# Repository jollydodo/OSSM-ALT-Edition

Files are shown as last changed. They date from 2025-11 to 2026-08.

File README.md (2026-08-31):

# OSSM ALT Edition
---
## 🎯 Overview

OSSM ALT Edition is a community-driven alternative version of the well-known [OSSM](https://github.com/KinkyMakers/OSSM-hardware) platform. A lot of time and effort has gone into this project. This has been possible thanks to all the previous work that has been done and several community members that helped test this. Do note that we are still in 'beta testing' phase and that you may run into issues. Please provide feedback to help improve the project. This project represents a ground-up redesign focused on:

- **Modern Power Delivery**: Custom 28V 140W USB-C PCB with comprehensive protection circuits
- **Simplified Assembly**: All-in-one clean design with easily sourceable components
- **European Sourcing**: BOM optimized for availability in Europe
- **Enhanced Performance**: Support for MGN12H and MGN15H rails with support for belts up to 15mm belt.
- **Open Source**: Fully open hardware

***Links***: KM [Discord community](https://kinkymakers.com) & [Ko-Fi](https://ko-fi.com/dododesigns) (for contributions / buying boards)

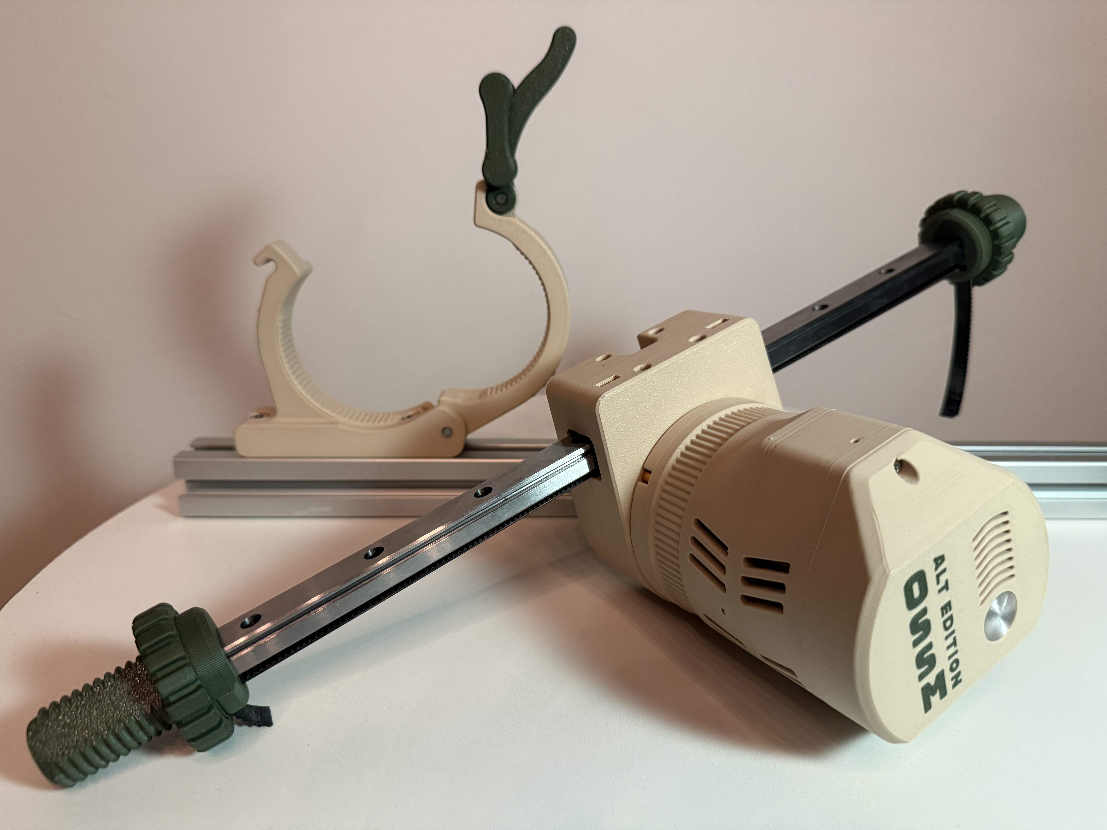
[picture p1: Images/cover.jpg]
MGN15H version with new clamp


<sub>**Notice**: This version was developed without any involvement of the original OSSM / Research and Desire members. However, none of this would have been possible without their prior work which is greatly appreciated. Especially the work of [ArmpitMFG](https://github.com/armpitMFG) has been a great inspiration. </sub>

---

## ✨ Key Features

### Hardware Improvements
- **Custom 28V USB-C PCB** with extensive protection circuits
  - Over/under voltage protection
  - Reverse current protection
  - ESD protection on all exposed ports
  - Inrush current limiting
  - Hybrid polymer capacitors for stable power
  - Brake Chopper Add-On 360Watt
- **Dual Rail Options**
  - MGN15H for heavy-duty applications (up to 15mm belts)
  - MGN12H for lighter builds (up to 12mm belts)
- **Efficient Travel**: Rail length minus 150mm usable stroke
- **Compatible with Pitclamp Mini** and includes optimized alternative design with dowels

### Electronics & Firmware
- **ESP32-S3** microcontroller with integrated RS485 controller
- **WS2812 Status LED** (firmware support pending)
- **Made for [OSSM Rust](https://github.com/orange-gem/ossm-rs)** firmware
- Compatible with step/dir control for original firmware adaptation
- **Optional Brake Chopper PCB** for enhanced safety

### Design Philosophy
- Optimized for 3D printing (minimal supports required)
- Common, easily sourceable components
- Clean, simple assembly
- Comprehensive protection systems

---
  
## 📦 Bill of Materials

A comprehensive BOM with descriptions and links can be found [here](Assembly-Info/BOM-OSSM-ALT.csv). However, the parts below are a quick summary everything you need for building this complete version:

| **Part** | **Description** | **Costs** |
| --- | --- | ----- |
| 57AIM30 | Motor | €110  |
| MGN15H Rail | Rail 40cm | €25 |
| Or MGN12H Rail | Rail 40cm | €21 |
| 625RS Bearing  | Belt Bearings | €15 |
| M5 Bolts | Complete kit | €12 |
| M3 Bolts | Complete kit | €12 |
| Dowel Pins | Precision pins | €10 |
| GT2 Belt | 50cm | €15 |
| GT2 20T pulley | 15mm | €10 | 
| Filament  | Max 500g | €20 |
| OSSM ALT 28V PCB | Designs available for self-sourcing or buy through me to support this project. | €40 |
| **Total** | Rough approximation. Check BOM for details. | €270  |

📋 **[Complete BOM with part numbers and links](Assembly-Info/BOM-OSSM-ALT.csv)**

> **Note**: You will also need a remote control device. Compatible options include:
> - Official R&D remote
> - iOS/Android apps
> - Web control interface
> - M5 Remote (check firmware compatibility)

---

## 3D Printing Tips

500 grams of filament should be enough to complete the whole build including the main pitclamp (350 without). It is optimized as much as possible for 3D printing with only 1 part requiring a small amount of supports. The filament type should not matter for most standard build, but heavy users might want to rely on something sturdier like tough-PLA, PET-G, ASA or PC. The test builds have been printed with standard Bambulab basic PLA (Not matte/silk). 

**Filament Required**: ~500g for complete build including Pitclamp

**Recommended Materials**:
- **Standard Use**: PLA, PLA+
- **Heavy Use**: Tough-PLA, PETG, ASA, PC

**Important**: Follow the [detailed 3D printing guide](Assembly-Info/Print-Manual/README.md) carefully to ensure proper fit and function.

**Print Options**:
- Standard version (no branding)
- Multi-color branded version (AMS/toolchanger compatible)
- Single-color embossed version

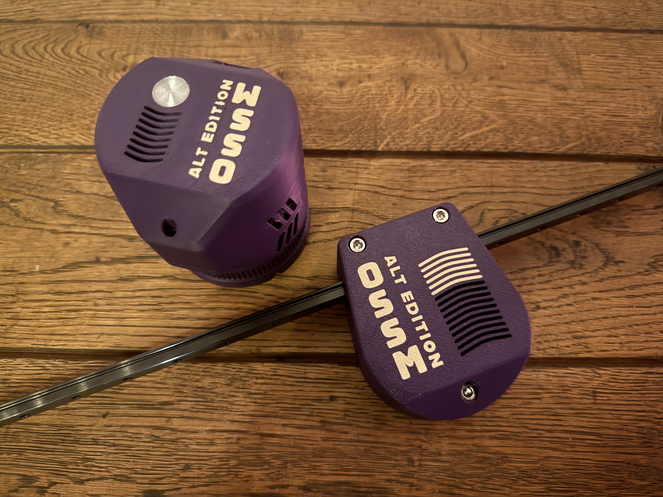
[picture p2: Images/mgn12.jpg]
MGN12H Light version


---
## Assembly:

📺 **Video Assembly Guides**:
- [Part 1](https://youtu.be/EqzNXQzpHu0) 
- [Part 2](https://youtu.be/FnY4Sz64H2A) 

📖 **Written Assembly Guide**: In development

❓ **Frequently asked**: [How do I install the brake chopper?](#how-do-i-install-the-brake-chopper)

💬 **Need Help?** Join the KM [Discord community](https://kinkymakers.com) for assembly support and questions (Look for the OSSM ALT Project).

---

## 🔌 Main PCB Specifications

Most work has gone into this PCB. My vision for this Machine/PCB is that groups of people will self-source this PCB. From 10+ pieces this makes sense, so as long as you can find 10 people you should be able to buy this at an affordable price. The rest of the machine can be printed and uses off the shelf parts. I will also sell these boards for people that only need 1 PCB and want to help support this project (please not that a lot of my own money has gone into this and any support is greatly appreciated ([Ko-Fi](https://ko-fi.com/dododesigns))

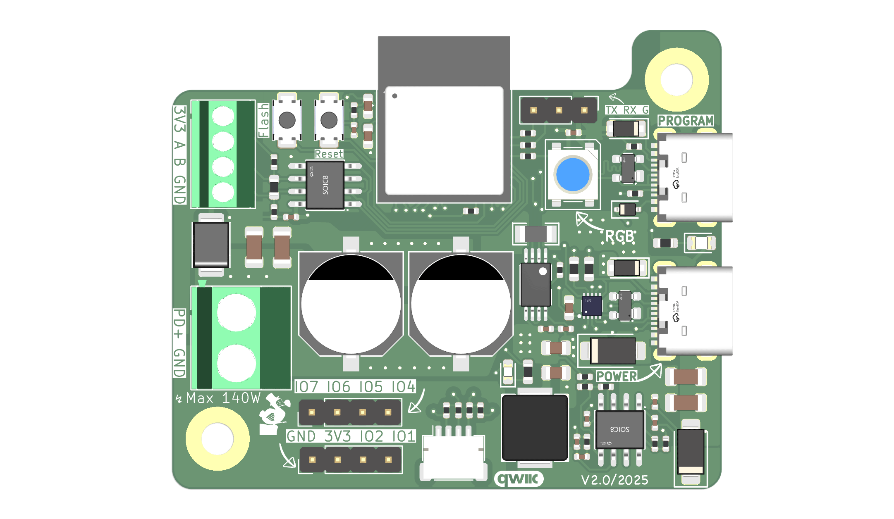
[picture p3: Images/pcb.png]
28V PCB


### Technical Features

- **Power**: CH224Q for 28V USB-C PD 3.2 negotiation
- - Continuous 140Watt capable with 4 layer optimized PCB design (load tested)
- **Controller**: ESP32-S3 microcontroller with onboard antenna
- **Communication**: Integrated RS485 controller
- **Power Protection**:
  - Hybrid polymer capacitors
  - Inrush current limiting
  - Over/under voltage protection
  - Reverse current protection
- **Additional Features**:
  - Dedicated USB-C debugging port
  - ESD protection on all exposed ports
  - WS2812 status LED
  - Brake chopper expansion support

**Design Tool**: KiCAD 9  
**Manufacturing**: Optimized for major PCB fabrication houses

### Optional Brake Chopper Add-on

Brake PCB

Enhanced protection for heavy-duty use:
- **Dissipation**: 12W continuous, 360W short-term spikes
- **Protection Threshold**: 33V (protects 36V TVS diode)
- **Purpose**: Back-EMF spike suppression
- **Recommended For**: Heavy users and added safety margin

This was mainly a fun side project for me which also adds functionality. It is basically an improved version of a Pololu Shunt Regulator, but completely redesigned with an on-board gate driver, 12V LDO, and 12watts of power resistors (2 sides assembly up to 24watt). This PCB was designed to be very cheap and easy to produce. 

Assembly PCB

> 🔧 **Installing it?** See [How do I install the brake chopper?](#how-do-i-install-the-brake-chopper) in the FAQ.

---

## ❓ FAQ

### How do I install the brake chopper?

There are **two** ways to connect the brake chopper to the main PCB. Both are electrically identical — the brake chopper simply sits in parallel with the motor supply.

#### Option 1: Screw terminal (recommended)

Simply put the brake chopper wires into the **same green screw terminal** as the motor power wires: the red (+) wire together with the motor's red wire, and the black (GND) wire together with the motor's black wire. Twist the two wires of each pair together, insert them into the terminal and tighten the screw.

This requires no soldering on the main PCB at all and is the option I recommend for everyone.

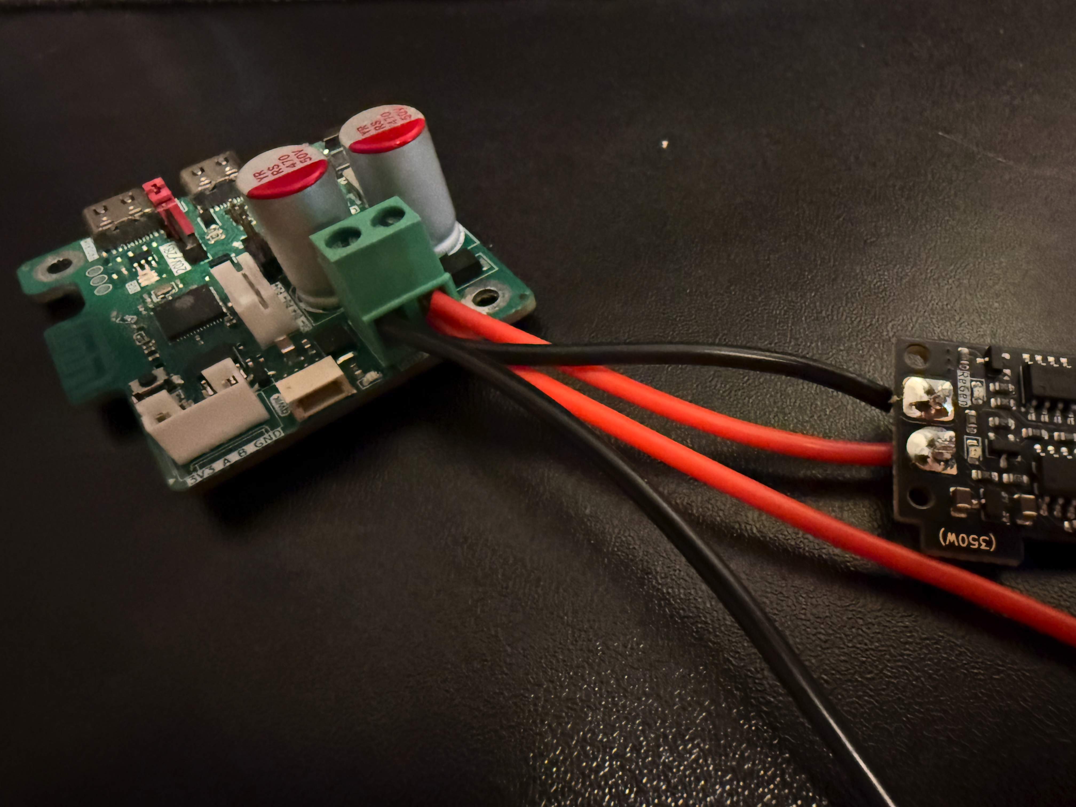
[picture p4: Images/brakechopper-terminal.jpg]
Brake chopper in the screw terminal


<video src="https://github.com/jollydodo/OSSM-ALT-Edition/raw/main/Images/brakechopper-install.mp4" controls width="640"></video>

📺 [Watch the short installation video](https://github.com/jollydodo/OSSM-ALT-Edition/raw/main/Images/brakechopper-install.mp4) *(if the player above does not load)*

#### Option 2: Solder to the dedicated pads

If you don't like doubling up wires in the screw terminal, the main PCB has **two dedicated pads on the back** for the brake chopper, marked `Brake` (`VIN` and `GND`). Solder the red wire to `VIN` and the black wire to `GND`.

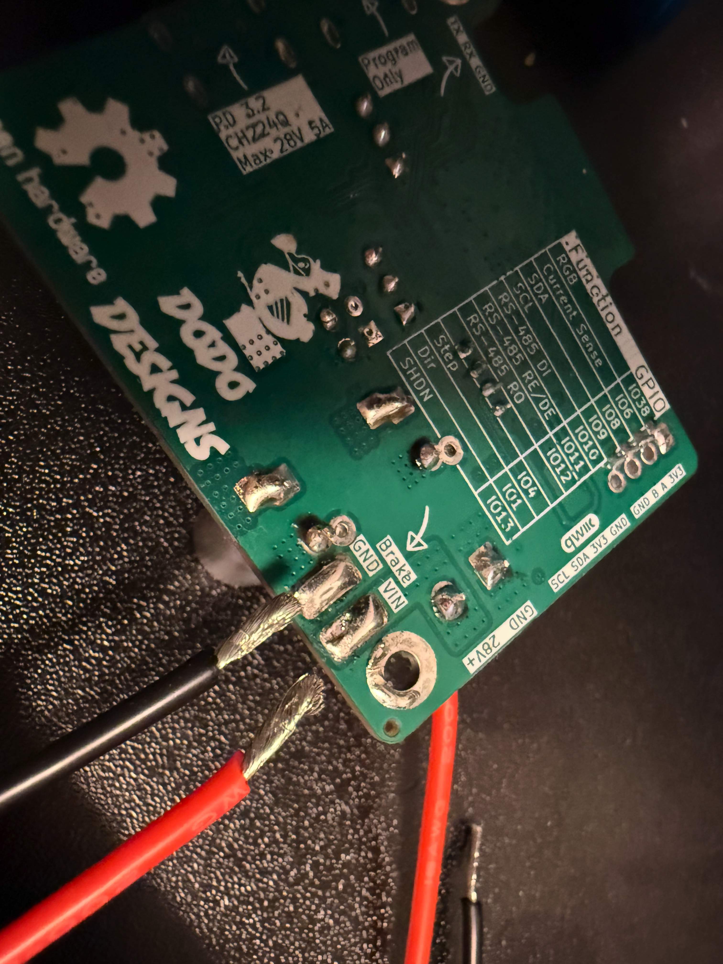
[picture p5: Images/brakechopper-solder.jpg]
Brake chopper soldered to the dedicated pads


> ⚠️ **At your own risk.** This is a 4-layer PCB with large copper planes that pull a lot of heat away from the joint, so you need a decent soldering iron (and patience). Double-check that you have not accidentally bridged anything before applying power.

---
## 🔋 Compatible Power Sources

This design is focused around PD, so it only makes sense to provide some options that are tested.

> **Important**: Use a USB-C cable with E-marker chip for >3A current. Standard cables will limit performance.

### Tested & Confirmed

| Device | Type | Rating | Status | Recommended | Rating | Notes |
|---|---|---|---|---|---|-----|
| [Apple 140W USB-C Adapter](https://www.apple.com/nl/shop/product/mw2m3zm/a/usb%E2%80%91c-lichtnetadapter-van-140-w) | Wall Adapter | 28V / 5A (140W) | 🔬 Tested | ✅ Recommended| ★★★★★ (5)| Excellent reliability and quality, Only ~€60 (will likely not work with other pcb's besides the OSSM ALT since it requires inrush current protection) |
| [Ugreen 200W Powerbank](https://eu.ugreen.com/products/ugreen-nexode-power-bank-200w-25000mah) | Powerbank | 28V / 5A (140W) | 🔬 Tested| ✅ Recommended|★★★★★ (5)| Great portable option that negotiates with almost any chip. Best power bank I have tested.|
| [Ugreen Nexode 145W Powerbank 25000mAh](https://nl.ugreen.com/products/ugreen-140w-power-bank-145w-max-25000mah-externe-batterij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) | Powerbank | 28V / 5A (140W) | 🔬 Tested | ✅ Recommended| ★★★★★ (5)| Tested by community member **Frayd**. Portable option in the same Nexode line as the 200W model above. |
| [Anker 140W Wall Adapter](https://www.anker.com/products/a2697-anker-charger-140w-4-port) | Wall Adapter | 28V / 5A (140W) | 🔬 Tested| ✅ Recommended|★★★★☆ (4)| Works well, but you will definitely feel it get hot at prolonged 140W and after 20 minutes or so it will lower the power to cool down. 100Watts continuous is fine so for the gold motor there are no problems. I have yet to see a supported motor that pulls 140W continuous. 
| [Sitecom 140W Wall adapter](https://www.action.com/nl-nl/p/3221194/sitecom-usb-wandoplader/) | Wall Adapter | 28V / 5A (140W)|🔬 Tested | ✅ Recommended| ★★★★☆ (4) | Cheapest adapter of the list (~€20). Did not do any extensive testing yet, but it negotiates 28V and 20V fine. I was also able to load test it at 140W and you can feel it get warmer similar to the Anker one, but it seems to hold up fine. At it's price point it is probably a very good deal (even comes with a cable), but we don't know if it's easy to source since right now it's sold at 'action' which normally changes its inventory quite quickly. 
| [Ugreen 100W Wall Adapter](https://www.amazon.nl/dp/B091TV6LWN) | Wall Adapter | 20V / 5A (100W) | 🔬 Tested | ⚠️ Lower Power|★★★☆☆ (3) |Works okay, but do notice that this one does not support 28V. If you have the OSSM-Alt pcb at 28V and still try to power it, it will work but negotiates down to 20V. |
| [Framework 180W Adapter](https://frame.work/nl/en/products/16-power-adapter?v=FRANCR000F) | Wall Adapter | 36V / 5A (180W) | 🔬 Tested | ⚠️ Lower Power | ★★★☆☆ (3) | Quality wise I believe this is a good adapter, but it has a lot of difficulty negotiating with several common cheap PD chips. So it won't negotiate above 20V on the OSSM-ALT PCB and it also does not seem to support I2C with this chip either. Therefore, not really recommended unless you already have it and just power a motor at max 100W. 
| Apple 67W Adapter | Powerbank | 20V / 3.3A (67W) | 🔬 Tested | ⚠️ Lower Power | ★★☆☆☆ (2.5) | Negotiates well and also supports I2C negotiation. 67W is however on the lower side, so this is definitely not recommended for heavy usage. Still, this was the adapter I first tested my OSSM with and from my experience 67W is enough for most light play.  |
| Xiaomi Mi 50W | Powerbank | 20V / 2A (40W) | 🔬 Tested | ⚠️ Low Power | ★★☆☆☆ (2) | Not recommended. Negotiates well, but low power. Still for a very light weight OSSM it might. be fine.  |

**Have you tested another power source?** Please share your results!

---

## ❤️ Support the Project

If you've built an OSSM ALT and want to support continued development:

### Financial Support

- **PCB Purchase**: Buy boards from me to support the project (Discord PM, Ko-Fi (soon))
- **Buy a hardware kit**: If there is enough demand, I might start selling some hardware kits 
- **Donations**: [Ko-Fi](https://ko-fi.com/dododesigns) *(or contact me on Discord)*

### Non-Financial Support

- ⭐ **Star this repository** to increase visibility
- 📢 **Share the project** with your community
- 📸 **Share your build** with photos and feedback on Discord
- 📖 **Contribute documentation** and improvements

teaser

---

## 📜 License

This project is **Open Source Hardware**.

All hardware design files (including PCB schematics, layouts, and 3D mechanical design files) are licensed under the **CERN Open Hardware Licence Version 2 – Strongly Reciprocal (CERN-OHL-S-2.0)**.

You are free to:
- Use, study, modify, and manufacture this design

Under the following conditions:
- **Attribution** must be given to the original author(s)
- **All modified versions and derivatives must be released under the same license**
- **Complete corresponding source files must be made available**

---

## 🙏 Acknowledgments

Special thanks to:

### Core Contributors
- **Orange-gem & Nakata** - OSSM Rust firmware development and invaluable feedback
- **Beta Testers** - All community members who tested and provided feedback

### Inspiration & Prior Art
- **[armpitMFG](https://github.com/armpitMFG)** - Front/end effector designs and Pitclamp Mini
- **Original OSSM / R&D Team** - Foundation and inspiration for this project

### Community
- All contributors who have improved this design
- Discord community members providing support and feedback

---

## ⚠️ Disclaimer

This project is currently in **beta testing phase**. While extensively tested, you may encounter issues. Please provide feedback to help improve the project.

**Safety**: This is a DIY project involving motors and electronics. Build and use at your own risk. Ensure all safety precautions are followed during assembly and operation.

---

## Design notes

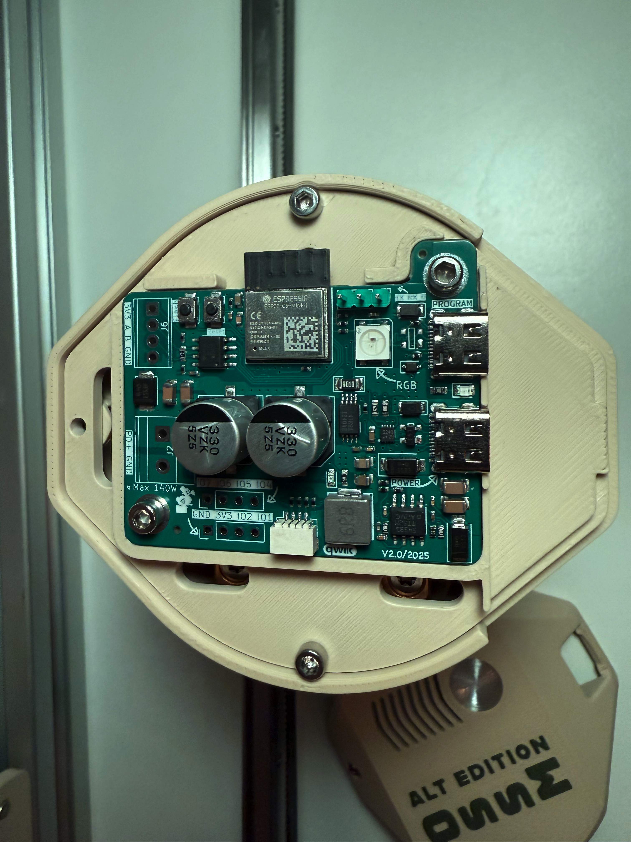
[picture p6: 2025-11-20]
Images/pcb2.jpg

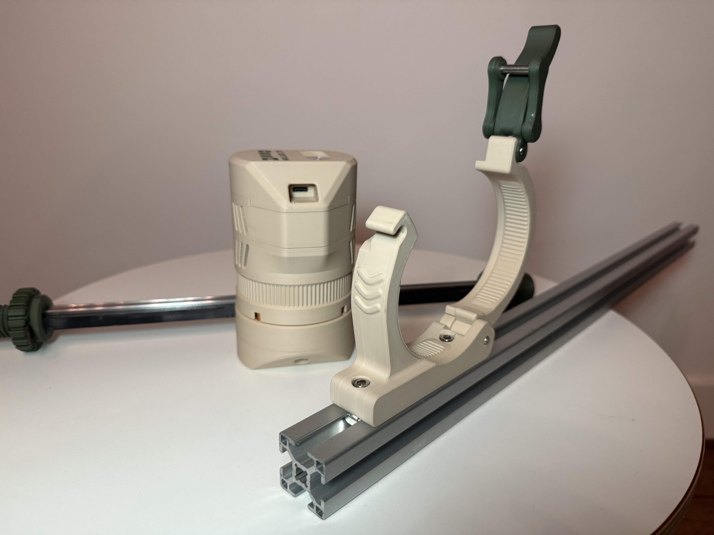
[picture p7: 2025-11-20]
Images/clamp.jpg

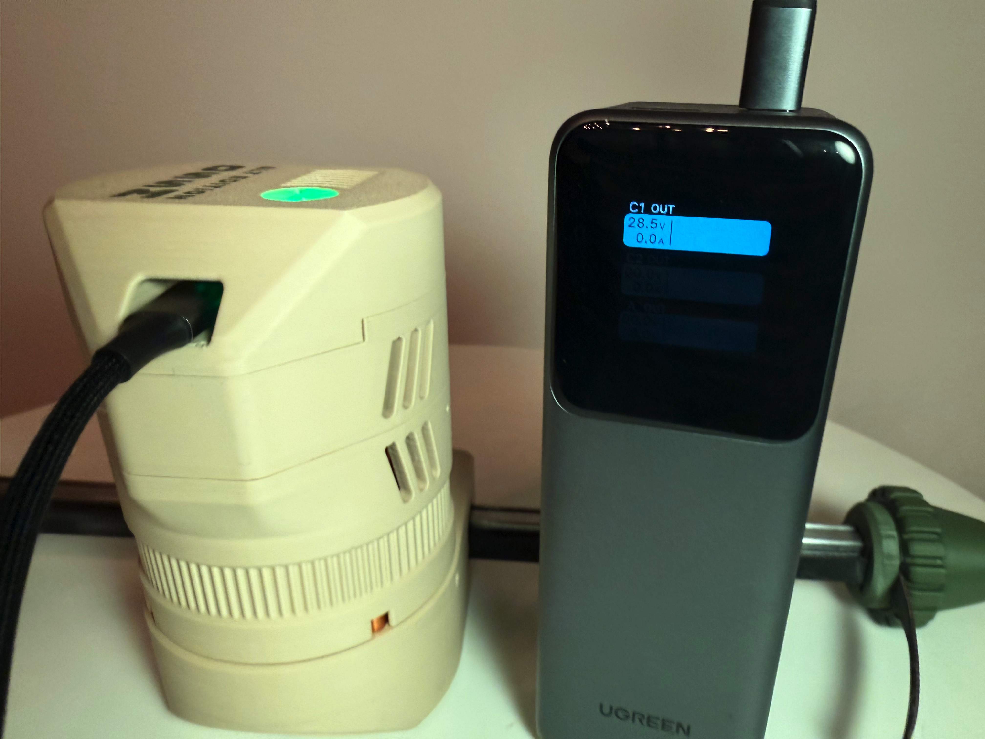
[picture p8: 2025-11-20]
Images/pd.jpg

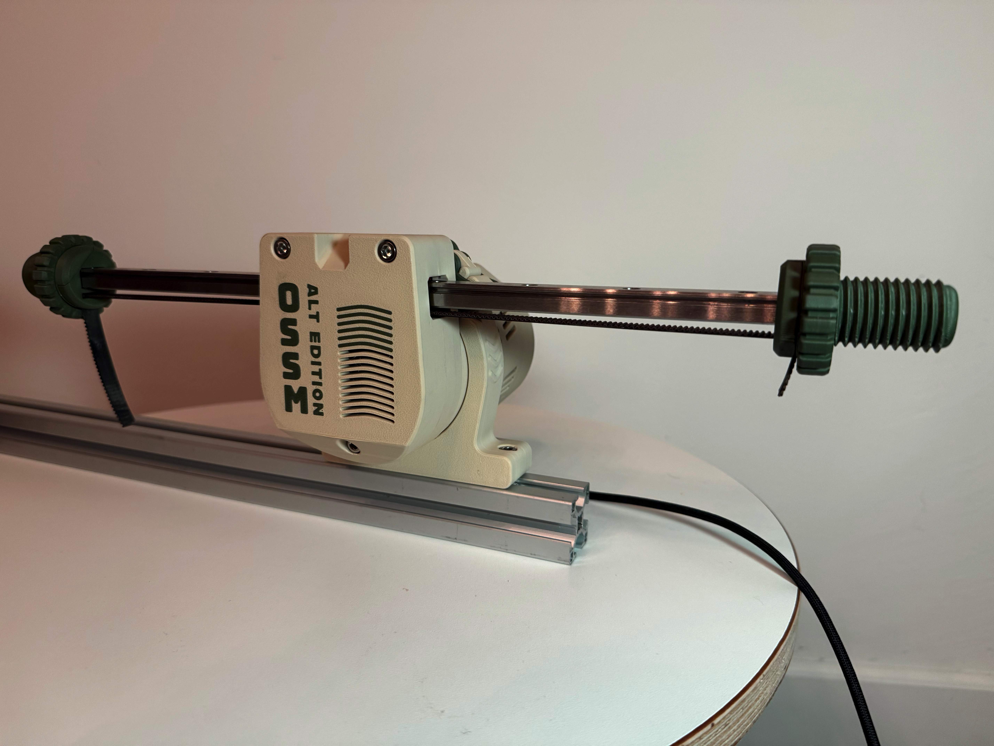
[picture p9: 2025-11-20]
Images/front.jpg

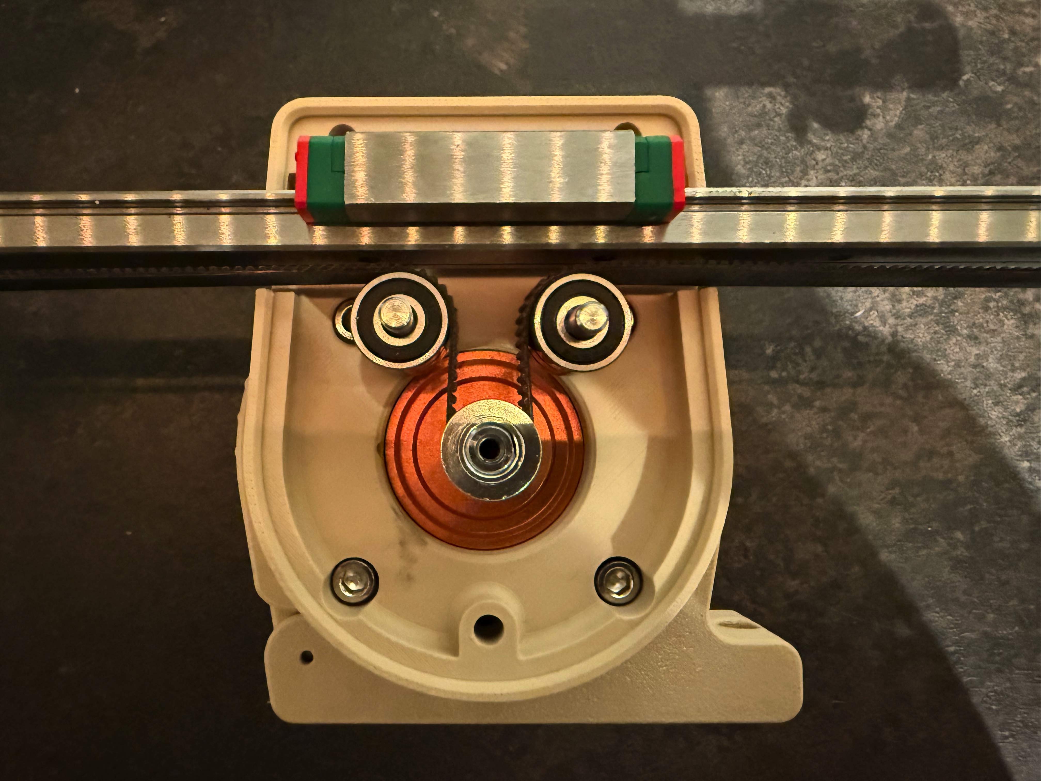
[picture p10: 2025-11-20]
Images/belt.jpg

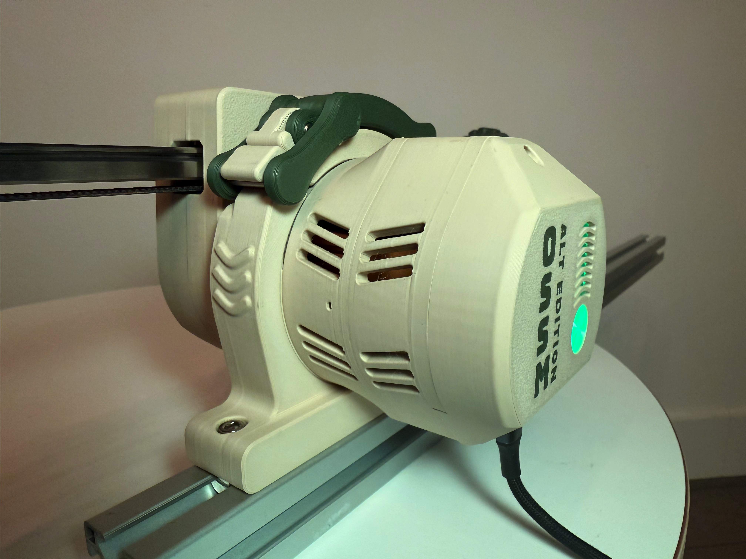
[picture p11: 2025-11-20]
Images/back.jpg

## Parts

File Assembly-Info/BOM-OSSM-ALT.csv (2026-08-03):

Assembly Category | Item No. | Part Name | Description | Quantity | Unit | Supplier Link | Unit Price | Total Price | Remarks
Belt Mechanics | B-0 | MGN-15H Rail | Tested with 400mm Length | 1 | pcs |  |  |  | The better the quality, the smoother it will be. Legitimate Hiwin is preferred, but Aliexpress alternatives will probably work as well. Usable length is approximately rail length - 150mm
Belt Mechanics | B-1 | 625-RS Bearings | Belt Bearings | 6 | pcs | https://www.amazon.nl/dp/B071RXC7FV? | €8.99 | €8.99 | 10 Pack
Belt Mechanics | B-2 | Precision Dowel Pin Kit | Dowel Pins for Bearings Kit | 1 | pcs | https://www.amazon.nl/dp/B0DR7R87KQ?th=1 | €12.99 | €12.99 | This pack contains all the pins needed for the complete OSSM ALT version including new Pit Clamp
Belt Mechanics | B-2B | M5*30 Dowel Pin (2 pins) | M5*30 dowel 5 pack | 1 | pcs | https://eu.store.bambulab.com/nl/products/d5-stainless-steel-dowel-pin?id=48706172092764 | €1.45 | €1.45 | This is sufficient if you are only making the belt mechanics without redesigned pitclamp. You do not need the dowel pin kit in this case
Belt Mechanics | B-3 | GT2 Belt (9-12 or 15mm) | Rail length + 10cm |  |  |  |  |  | Pick any GT2 belt that will fit your GT2 pulley. OSSM ALT version supports everything up to 15mm. 15mm gives the most grip
Belt Mechanics | B-4 | GT2 20T Pulley (15mm belt max) | Pulley for your belt size | 1 | pcs |  |  |  | Pick a pulley that fits your belt. A pulley that supports a 15mm belt has maximum performance, but 9 or 12mm will work as well
Belt Mechanics | B-5 | M5 Bolt Kit | M5 bolt kit for complete OSSM ALT | 1 | pcs | https://www.amazon.nl/dp/B0DPWYNDZF? | €11.99 | €11.99 | This kit contains all the M5 bolts that are needed for the complete OSSM Alt Edition including redesigned Pitclamp
Belt Mechanics | B-5B | M5*30 Head Cap Bolt | Front mount bolts | 2 | pcs |  |  |  | Only needed if you don't buy the M5 bolt kit
Belt Mechanics | B-5C | M5*20 Head Cap Bolt | Front mount bolts | 1 | pcs |  |  |  | Only needed if you don't buy the M5 bolt kit
Belt Mechanics | B-6 | M3 Bolt Kit | M3 bolt kit for complete OSSM ALT | 1 | pcs | https://www.amazon.nl/dp/B0B3MGZ7T2 | €8.88 | €8.88 | This kit contains all the M3 bolts that are needed for the complete OSSM Alt Edition
Motor / PCB Housing | C-0 | 57AIM30 motor | OSSM Motor | 1pcs |  |  | €100 |  | Around 100 euros including shipping and taxes to Europe
Motor / PCB Housing | C-1 | M3 Bolt Kit | M3 bolt kit for complete OSSM ALT | 1 | pcs | https://www.amazon.nl/dp/B0B3MGZ7T2 | €8.88 | €8.88 | This kit contains all the M3 bolts that are needed for the complete OSSM Alt Edition
Belt Mechanics | B-6B | M3*12 Head Cap Bolt | Rail bolts | 4 | pcs |  |  |  | Only needed if you don't buy the M3 bolt kit
Motor / PCB Housing | C-1B | M3*40 bolt | Housing bolts | 2 | pcs |  |  |  | Only needed if you don't buy the M3 bolt kit
Motor / PCB Housing | C-1C | M3*8 bolt | PCB Mount | 2 | pcs |  |  |  | Only needed if you don't buy the M3 bolt kit
Motor / PCB Housing | C-1D | M3*12 bolt | Top Cover Bolt | 1 | pcs |  |  |  | Only needed if you don't buy the M3 bolt kit
Motor / PCB Housing | C-2 | M5*30 bolt | Motor Fastening Bolts | 4 | pcs |  |  |  | Only needed if you don't buy the M5 bolt kit (also not needed if you are using the original OSSM belt mechanics/front)
Motor / PCB Housing | C-1E | M3 nuts | Captive Nuts | 5 | pcs |  |  |  | Only needed if you don't buy the M3 bolt kit
Motor / PCB Housing | C-2B | M5 nuts | Captive Nuts | 3 | pcs |  |  |  | Only needed if you don't buy the M5 bolt kit
Motor / PCB Housing | C-2C | M5 Lock nuts | M5 Motor lock nuts | 4 | pcs | https://www.toolstation.nl/borgmoeren/p12051 | €3.05 | €3.05 | You can also use regular nuts, but those might vibrate. This is also needed if you are using the original OSSM. The link is for 100 pieces
Motor / PCB Housing | C-3 | OSSM ALT version Custom PCB | Custom PCB for the ALT Version | 1 | pcs |  | TBD | TBD | All production files are available. If you source them yourself and order a minimum of 10, the price should drop to around 13 euros per piece, and to 10 euros at 20+
Redesigned Pitclamp | D-1 | Precision Dowel Pin Kit | Dowel Pins for Bearings Kit | 1 | pcs | https://www.amazon.nl/dp/B0DR7R87KQ?th=1 | €12.99 | €12.99 | This pack contains all the pins needed for the complete OSSM ALT version including new Pit Clamp
Redesigned Pitclamp | D-1B | M5*25 Dowel Pin (3 pins) | M5*25 dowel 5 pack | 1 | pcs | https://eu.store.bambulab.com/nl/products/d5-stainless-steel-dowel-pin?id=48706172059996 | €1.45 | €1.45 | Only needed if you don't buy the dowel pin kit
Redesigned Pitclamp | D-1B | M5*16 Dowel Pin (1 pins) | M5*16 dowel 5 pack | 1 | pcs | https://eu.store.bambulab.com/nl/products/d5-stainless-steel-dowel-pin?id=48706171994460 | €1.35 | €1.35 | Only needed if you don't buy the dowel pin kit
Redesigned Pitclamp | D-2 | M5*20 Head Cap bolt | Bolts to mount to 3030 extrusion | 2 | pcs |  |  |  | Only needed if you don't buy the M5 bolt kit
Redesigned Pitclamp | D-2 | 3030 extrusion M5 fastening nuts | M5 nuts for 3030 extrusion | 2 | pcs |  |  |  | Just pick what you have or what you can get. As long as it's M5 and fits 3030, it will work
Belt Clamp | E-1 | M3 nuts | M3 nut | 1 | pcs
Belt Clamp | E-2 | M3*16 head cap bolt | Optional for front mount | 1 | pcs |  |  |  | Optional to make sure it stays on, but not necessary since everything is tightened together by the belt
Other | F-0 | 3D print filament | 500g should be more than sufficient. |  |  |  |  |  | Pitclamp: 100g / Belt tensioning and toy mount: 63g / Belt mechanics: 117g / Main mechanics: 162g. Total: 442g

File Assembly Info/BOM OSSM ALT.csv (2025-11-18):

Assembly Category | Item No. | Part Name | Description | Quantity | Unit | Supplier Link | Unit Price | Total Price | Remarks
Belt Mechanics | B-0 | MGN-15H Rail | Tested with 400mm Length | 1 | pcs |  |  |  | The better the quality, the smoother it will be. Legitimate Hiwin is preferred, but Aliexpress alternatives will probably work ass well. Usable length is approximately rail length - 150mm
Belt Mechanics | B-1 | 625-RS Bearings | Belt Bearings | 6 | pcs | Amazon Link | €8.99 | €8.99 | 10 Pack
Belt Mechanics | B-2 | Precision Dowel Pin Kit | Dowel Pins for Bearings Kit | 1 | pcs | Amazon Link | €12.99 | €12.99 | This pack contains all the pins needed for the complete OSSM ALT version inclduding new Pit Clamp
Belt Mechanics | B-2B | M5*30 Dowel Pin (2 pins) | M5*30 dowel 5 pack | 1 | pcs | Bambulab Link | €1.45 | €1.45 | This is sufficient If you are only making the belt mechanics withouth redesigned pitclamp. You do not need the dowel Pin kit in this case
Belt Mechanics | B-3 | GT2 Belt (9-12 or 15mm) | Rail length + 10cm |  |  |  |  |  | Pick any GT2 Belt that will fit your GT2 pulley. OSSM ALT version support everything up to 15mm. 15MM gives the most grip
Belt Mechanics | B-4 | GT2 20T Pulley (15mm belt max) | Pulley for your belt size | 1 | pcs |  |  |  | Pick a pulley that fits your belt. A pulley that supports a 15mm belt has maximim performance, but 9 or 12mm will work as well
Belt Mechanics | B-5 | M5 Bolt Kit | M5 bolt kit for complete OSSM ALT | 1 | pcs | Amazon Link | €11.99 | €11.99 | This kit contains all the M5 bolts that are needed for the complete OSSM Alt Edition including redesigned Pitclamp
Belt Mechanics | B-5B | M5*30 Head Cap Bolt | Front mount bolts | 2 | pcs |  |  |  | Only needed if you don't buy the M5 bolt kit
Belt Mechanics | B-5C | M5*20 Head Cap Bolt | Front mount bolts | 1 | pcs |  |  |  | Only needed if you don't buy the M5 bolt kit
Belt Mechanics | B-6 | M3 Bolt Kit | M3 bolt kit for complete OSSM ALT | 1 | pcs | Amazon Link | €8.88 | €8.88 | This kit contains all the M3 bolts that are needed for the complete OSSM Alt Edition
Motor / PCB Housing | C-0 | 57AIM30 motor | OSSM Motor | 1pcs |  |  | € 100 |  | Around 100 euro's including shipping / taxes to Europe
Motor / PCB Housing | C-1 | M3 Bolt Kit | M3 bolt kit for complete OSSM ALT | 1 | pcs | Amazon Link | €8.88 | €8.88 | This kit contains all the M3 bolts that are needed for the complete OSSM Alt Edition
Belt Mechanics | B-6B | M3*12 Head Cap Bolt | Rail bolts | 4 | pcs |  |  |  | Only needed if you don't buy the M3 bolt kit
Motor / PCB Housing | C-1B | M3*40 bolt | Housing bolts | 2 | pcs |  |  |  | Only needed if you don't buy the M3 bolt kit
Motor / PCB Housing | C-1C | M3*8 bolt | PCB Mount | 2 | pcs |  |  |  | Only needed if you don't buy the M3 bolt kit
Motor / PCB Housing | C-1D | M3*12 bolt | Top Cover Bolt | 1 | pcs |  |  |  | Only needed if you don't buy the M3 bolt kit
Motor / PCB Housing | C-2 | M5*30 bolt | Motor Fastening Bolts | 4 | pcs |  |  |  | Only needed if you don't buy the M5 bolt kit (Also not needed if you are using the original OSSM belt mechanics / front)
Motor / PCB Housing | C-1E | M3 nuts | Captive Nuts | 5 | pcs |  |  |  | Only needed if you don't buy the M3 bolt kit
Motor / PCB Housing | C-2B | M5 nuts | Captive Nuts | 3 | pcs |  |  |  | Only needed if you don't buy the M5 bolt kit
Motor / PCB Housing | C-2C | M5 Lock nuts | M5 Motor lock nuts | 4 | pcs | Toolstation Link | €3.05 | €3.05 | You can also use regular nuts, but those might vibrate. This is also needed if you are using the original OSSM. I've deleted the original coupling nuts that were an uncommon size). The link is for 100 pieces
Motor / PCB Housing | C-3 | OSSM ALT version Custom PCB | Custom PCB fore the ALT Version | 1 | pcs |  | TBD | TBD | All production files are available. I'm looking into supplying some of these in Europe, but if you source them yourself and order a minimum of 10 you should get the price down to around 13 euro's a piece. It goes down to 10 at 20+.
Redesigned Pitclamp | D-1 | Precision Dowel Pin Kit | Dowel Pins for Bearings Kit | 1 | pcs | Amazon Link | €12.99 | €12.99 | This pack contains all the pins needed for the complete OSSM ALT version inclduding new Pit Clamp
Redesigned Pitclamp | D-1B | M5*25 Dowel Pin (2 pins) | M5*25 dowel 5 pack | 1 | pcs | Bambulab Link | €1.45 | €1.45 | Only needed if you don't buy the dowel pin kit
Redesigned Pitclamp | D-1B | M5*16 Dowel Pin (1 pins) | M5*16 dowel 5 pack | 1 | pcs | Bambulab Link | €1.35 | €1.35 | Only needed if you don't buy the dowel pin kit
Redesigned Pitclamp | D-2 | M5*20 Head Cap bolt | Bolts to mount to 3030 extrusion | 2 | pcs |  |  |  | Only needed if you don't buy the M5 bolt kit
Redesigned Pitclamp | D-2 | 3030 extrusion M5 fastening nuts | M5 nuts for 3030 extrusion | 2 | pcs |  |  |  | Just pick what you have / what you can get. There are many variant, but as long as it's m5 and fits 3030 it will work.
Belt Clamp | E-1 | M3 nuts | M3 nut | 1 | pcs
Belt Clamp | E-2 | M3*16 head cap bolt | Optional for front mount | 1 | pcs |  |  |  | Optional to make sure it stays on, but it is not necessary since everything should be tightened together by the blet
Other | F-0 | 3D print filament | 500g should be more than sufficient. |  |  |  |  |  | Pitclamp: 100 grams / Belt Tensioning and toy mount: 63 grams / Belt Mechanics: 117 gram / Main Mechanics: 162 grams, Total: 442 gram

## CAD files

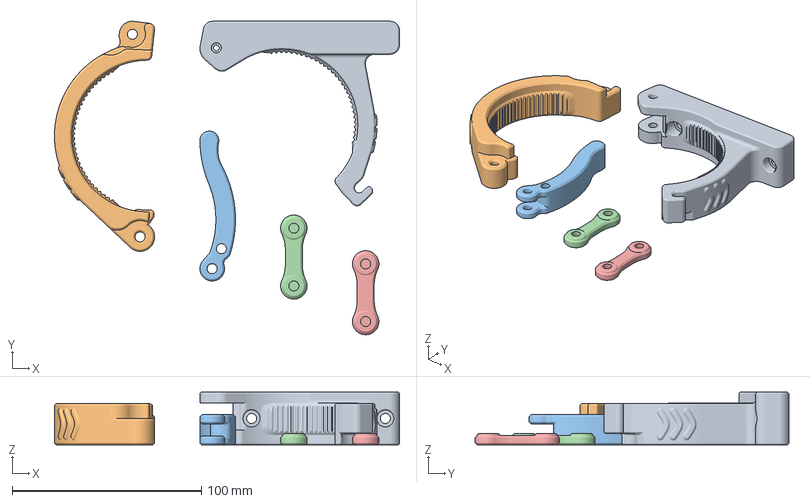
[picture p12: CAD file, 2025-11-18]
Hardware Design/Alternate Pitclamp Mini Mount/Complete Sliced Alternative Pitclamp.3mf
182.5 x 165.9 x 28.0 mm
Lower.stl
Upper.stl
Handle.stl
Dogbone (x2).stl x 2

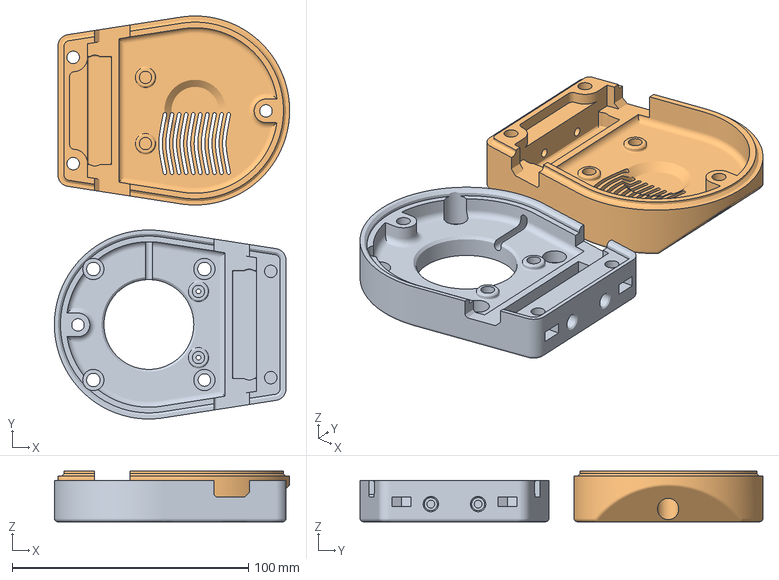
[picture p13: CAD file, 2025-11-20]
Hardware Design/MGN12H Main Mechanics/complete (sliced) MGN12H Mechanics.3mf
99.6 x 170.6 x 21.5 mm
bab2.stl
Main Mount Top22

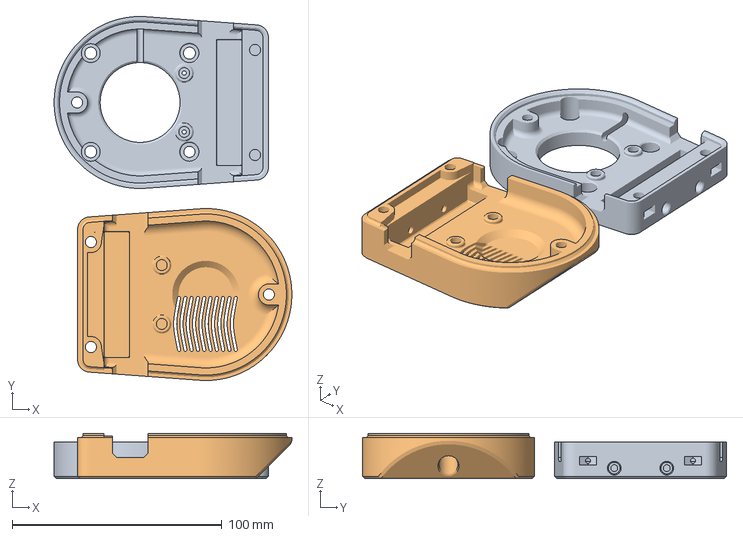
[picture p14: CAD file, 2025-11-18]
Hardware Design/MGN15H Main Mechanics/Complete (sliced) MGN15 Main Mechanics.3mf
113.2 x 173.4 x 21.5 mm
Rear
Belt Mechanics - Top

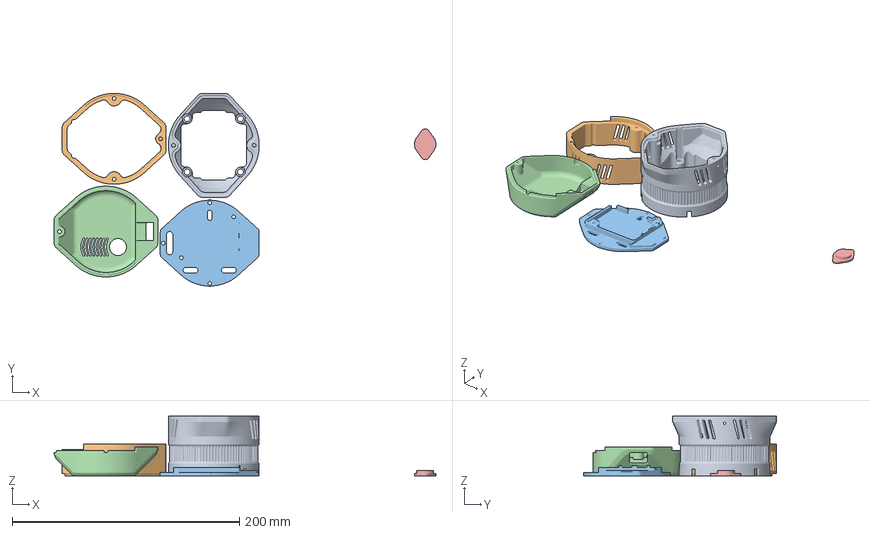
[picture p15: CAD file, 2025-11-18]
Hardware Design/Motor and PCB Housing/Complete (sliced) Motor Mount and PCB Housing.3mf
336.4 x 170.2 x 52.6 mm
Motor Mount - Main Clamp.stl
Motor Mount - Spacer Ring.stl
Motor Mount - PCB Holder.stl
Motor Mount - Top Cover
Motor Mount - Transparant LED Cover.stl

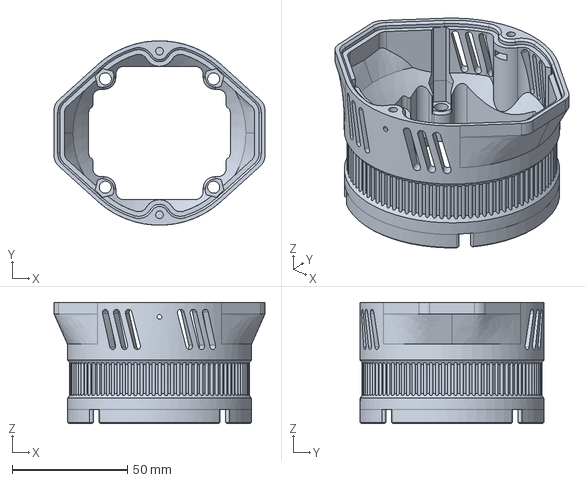
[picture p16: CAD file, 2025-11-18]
Hardware Design/Motor and PCB Housing/STEP/Motor Mount - Main Clamp.step
91.6 x 80.0 x 52.6 mm

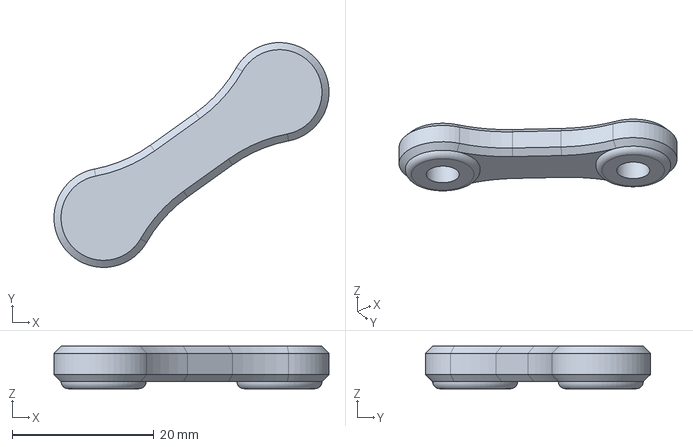
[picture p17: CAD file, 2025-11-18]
Hardware Design/Alternate Pitclamp Mini Mount/STEP/Dogbone.step
38.8 x 31.7 x 6.00 mm

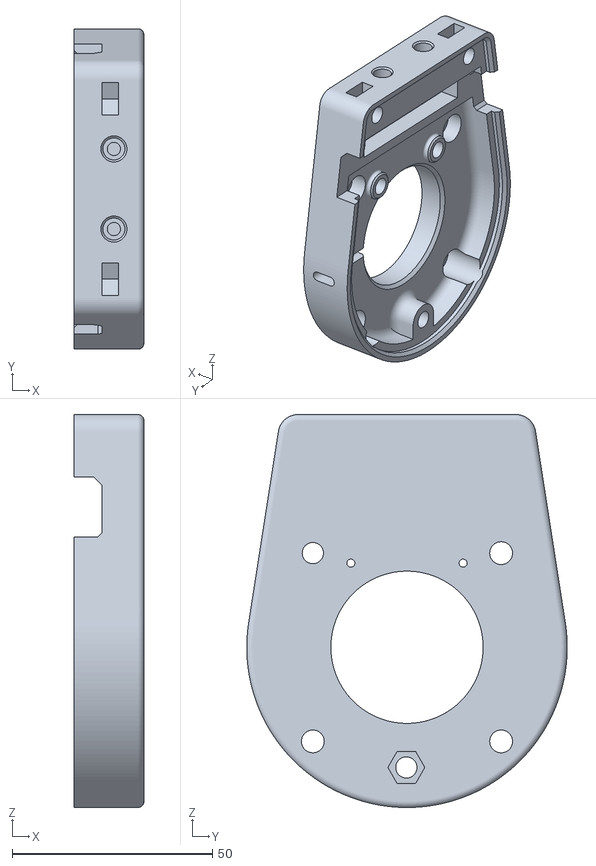
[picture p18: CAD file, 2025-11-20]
Hardware Design/MGN12H Main Mechanics/STL/Belt Mechanics - Rear.stl
17.4 x 80.0 x 98.1

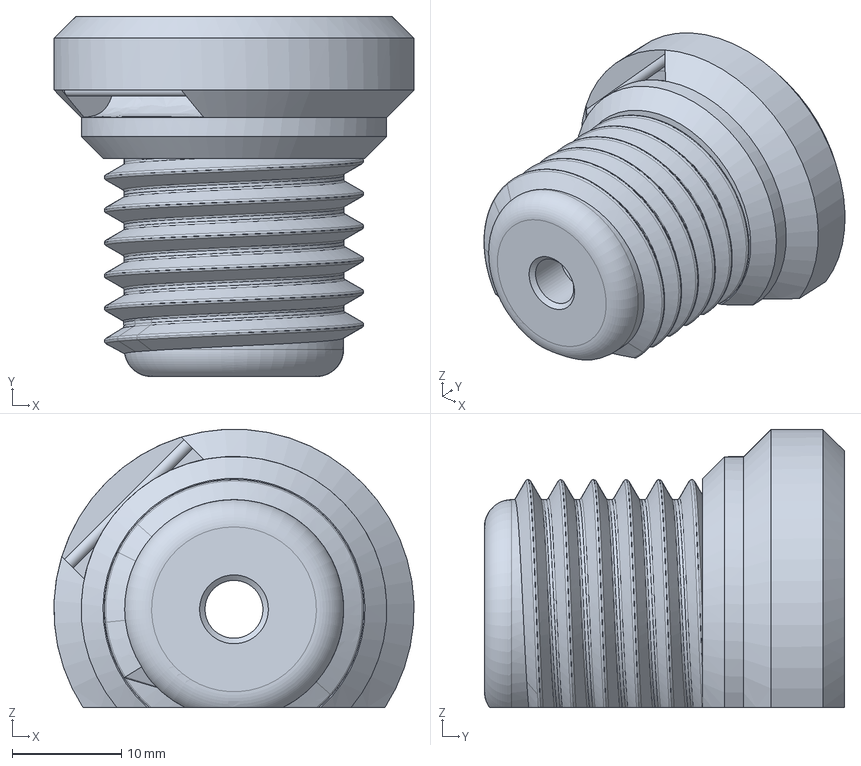
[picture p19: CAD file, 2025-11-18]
Hardware Design/MGN15H Belt Clamp and Toy Mount/STEP/Belt Tensioner.step
33.0 x 33.0 x 25.5 mm

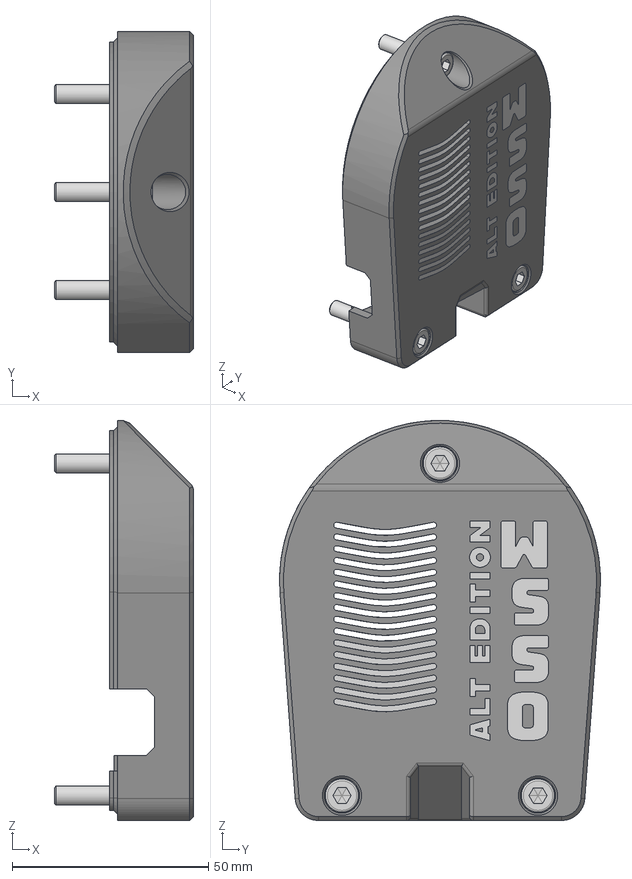
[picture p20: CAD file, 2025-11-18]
Hardware Design/MGN15H Main Mechanics/STEP/Belt Mechanics - Front.step
35.5 x 81.9 x 102.0 mm
BSHCS ANSI B18.3.1M - M3x0.5 x 12 Steel Grade 2 Plain x 2
BSHCS ANSI B18.3.1M - M5x0.8 x 30 Steel Grade 2 Plain x 2
BSHCS ANSI B18.3.1M - M5x0.8 x 20 Steel Grade 2 Plain

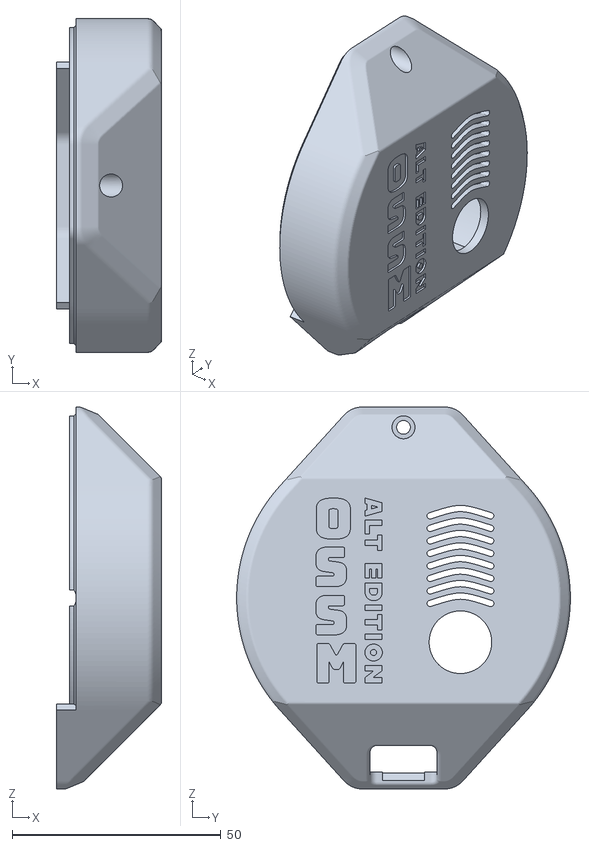
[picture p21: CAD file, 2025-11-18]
Hardware Design/Motor and PCB Housing/STL/Motor Mount - Top Cover - Single Color - No LED.stl
25.2 x 80.0 x 91.6

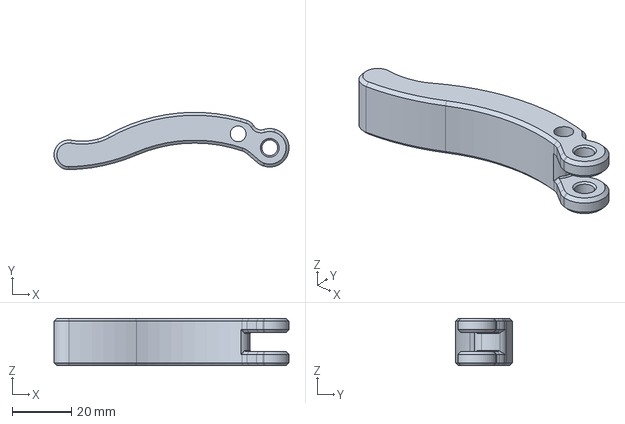
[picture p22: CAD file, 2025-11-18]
Hardware Design/Alternate Pitclamp Mini Mount/STEP/Handle.step
79.3 x 19.3 x 16.0 mm

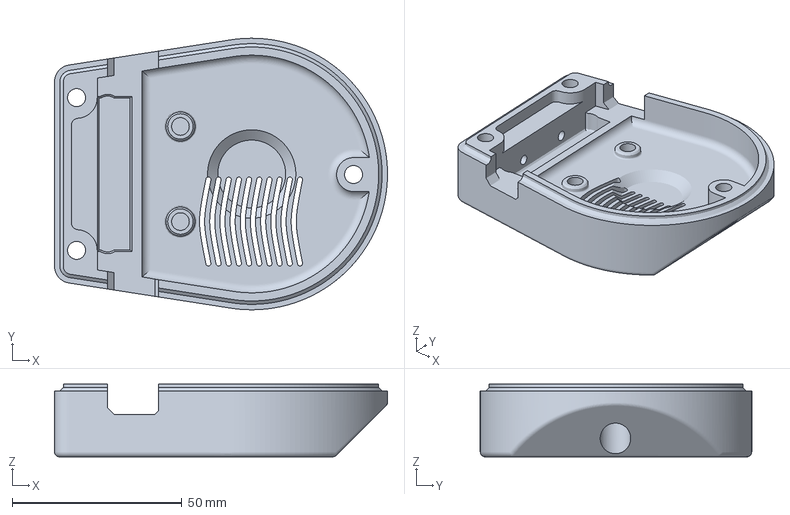
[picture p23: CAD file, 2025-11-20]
Hardware Design/MGN12H Main Mechanics/STL/Belt Mechanics - Front - Multicolor.3mf
98.1 x 80.0 x 21.5 mm

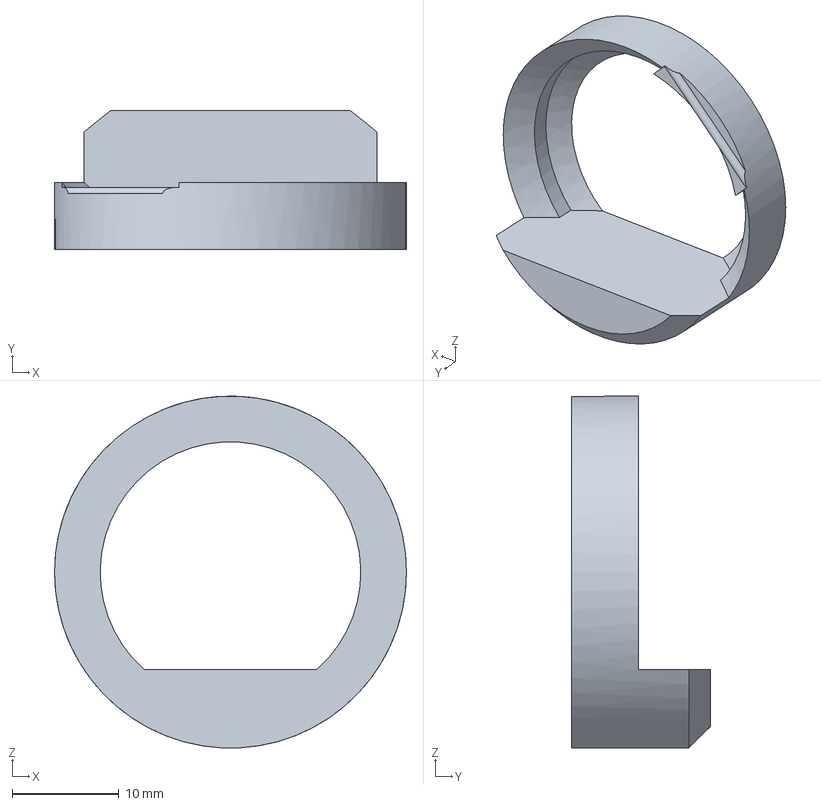
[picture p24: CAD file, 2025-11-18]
Hardware Design/MGN15H Belt Clamp and Toy Mount/STEP/Clamp.step
33.0 x 13.0 x 33.0 mm

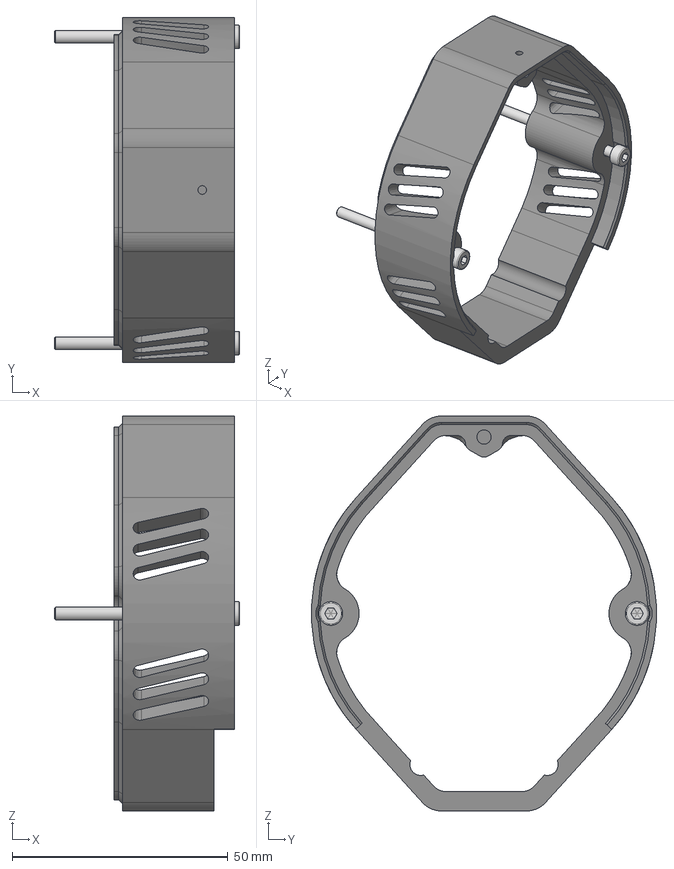
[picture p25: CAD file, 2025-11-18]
Hardware Design/Motor and PCB Housing/STEP/Motor Mount - Spacer Ring.step
43.0 x 79.9 x 91.6 mm
BSHCS ANSI B18.3.1M - M3x0.5 x 40 Steel Grade 2 Plain x 2

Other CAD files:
Hardware Design/Alternate Pitclamp Mini Mount/STL/Dogbone (x2).stl
Hardware Design/MGN15H Belt Clamp and Toy Mount/STL/Belt Clamp (x2).stl
Hardware Design/Motor and PCB Housing/STL/Motor Mount - Transparant LED Cover.stl
Hardware Design/Alternate Pitclamp Mini Mount/STEP/Lower.step
Hardware Design/Alternate Pitclamp Mini Mount/STEP/Upper.step
Hardware Design/Alternate Pitclamp Mini Mount/STL/Handle.stl
Hardware Design/Alternate Pitclamp Mini Mount/STL/Lower.stl
Hardware Design/Alternate Pitclamp Mini Mount/STL/Upper.stl
Hardware Design/MGN12H Main Mechanics/STL/Belt Mechanics - Front - Single.stl
Hardware Design/MGN15H Belt Clamp and Toy Mount/STEP/Belt Tension Cover.step
Hardware Design/MGN15H Belt Clamp and Toy Mount/STEP/Nut.step
Hardware Design/MGN15H Belt Clamp and Toy Mount/STL/Nut (x2).stl
Hardware Design/MGN15H Main Mechanics/STL/Belt Mechanics - Front - Multicolor.3mf
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

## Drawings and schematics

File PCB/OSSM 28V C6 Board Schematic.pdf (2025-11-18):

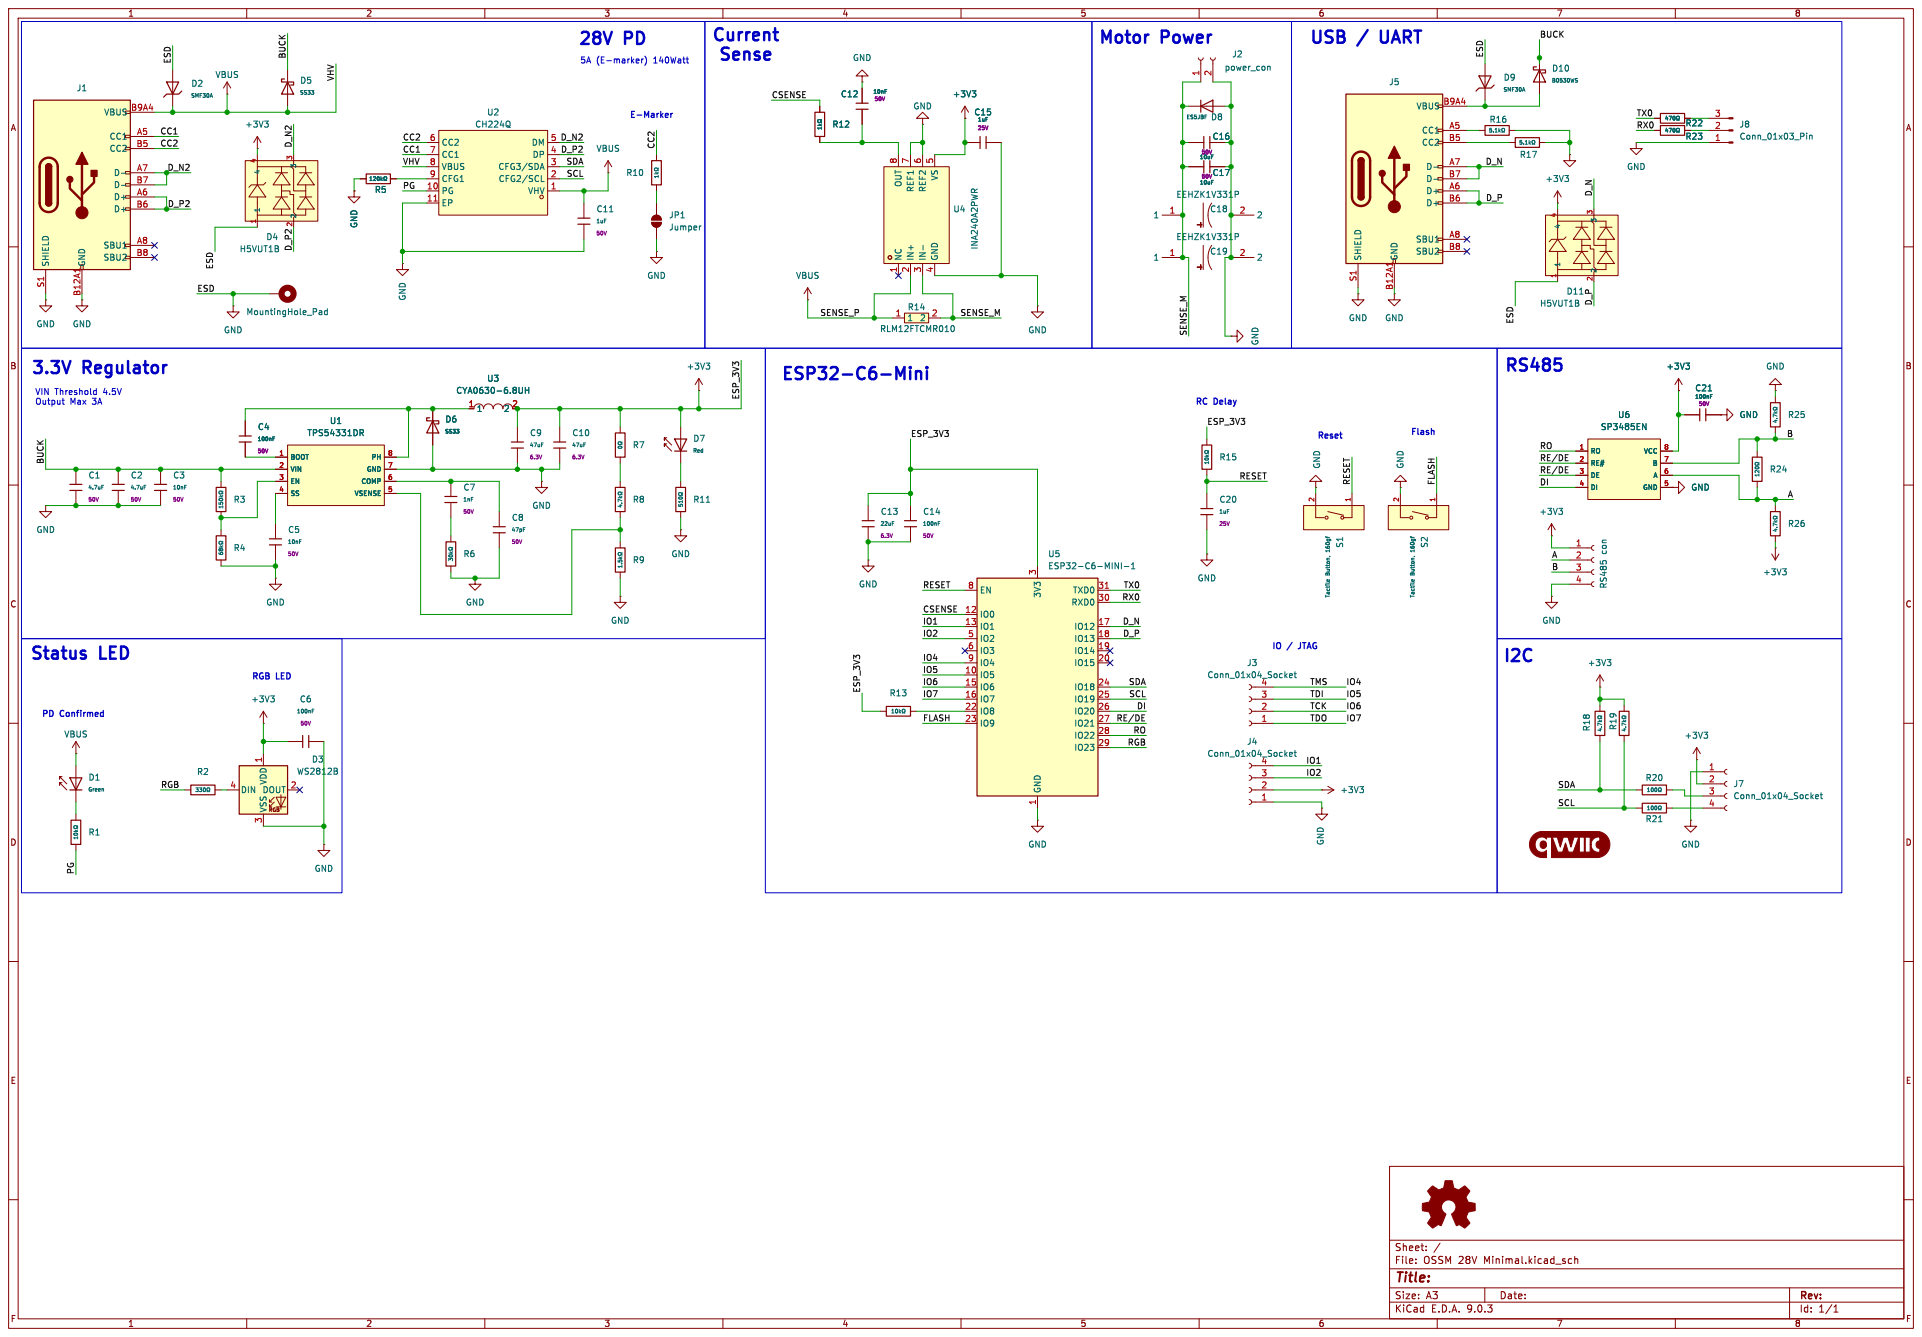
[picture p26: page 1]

1 S1 Tactile Button, 160gf GND GND

RC Delay VIN Threshold 4.5V Output Max 3A 3.3V Regulator

SCL RE/DEDI RO

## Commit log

2025-11-20 mgn12 version added
    [Belt Clamp (x2).stl, Belt Mechanics - Front - Multicolor.3mf, Belt Mechanics - Front - Single.stl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]
2026-08-03 Fixed BOM CSV rendering
    [BOM-OSSM-ALT.csv]
2026-08-03 Added brake chopper installation FAQ and new powerbank
